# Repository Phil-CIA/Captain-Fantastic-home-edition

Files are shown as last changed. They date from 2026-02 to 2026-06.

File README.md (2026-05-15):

# Captain Fantastic – Home Edition

Firmware and hardware files for a restored Captain Fantastic pinball machine running on ESP32.

## Repository Layout

| Path | Description |
|---|---|
| `src/` `include/` `data/` | **Legacy firmware** – working single-board ESP32 firmware with External Flash OTA |
| `Captain-v2/` | **Captain v2 firmware** – clean split-MPU architecture (control + matrix boards) |
| `hardware/` | KiCad schematics, gerbers, and board-design backups |
| `docs/` | Project documentation, setup guides, and handoff notes |
| `archive/` | Historical backups, experiments, and recovery copies |
| `music/` | Test audio files used with the music streaming server |

## PlatformIO Projects

This repo contains **multiple PlatformIO projects**:

### 1. Legacy Firmware (root)
- `platformio.ini` at the repository root
- Active environment: `combined_rtos`
- Targets a single ESP32 running gameplay, displays, sound, and OTA

### 2. Captain v2 shared source tree
- `Captain-v2/platformio.ini`
- Shared build definitions and source for split-MPU firmware
- Includes environments for control, matrix, and display-link variants
- Shared source only; not the current matrix bring-up source of truth
- Separates control logic and switch/lamp matrix scanning across two ESP32 boards

### 3. Captain v2 board-specific projects
- `Captain-v2-control/platformio.ini` (control board focused project)
- `Captain-v2-matrix/platformio.ini` (matrix board focused project)
- Both reference shared source under `Captain-v2/` and keep board workflows isolated
- Current active board workflows:
	- Matrix board: `Captain-v2-matrix`, env `captain_matrix_idf`, COM4
	- Control board: `Captain-v2`, env `captain_control`, COM5

> **VS Code tip:** Open the specific project folder you are actively working on (`Captain-v2-control/` or `Captain-v2-matrix/`) so tasks and upload settings stay board-specific.

## Current Development Focus

- Active matrix bring-up/runtime source of truth is `Captain-v2-matrix/src/matrix_app_main.cpp`
- Matrix MCU appears on I2C as a register-based peripheral at `0x24` (HT16K33-style model)
- Matrix/control communication path is now usable for gameplay bring-up:
	- control-side polarity normalization and stability filtering restored usable switch behavior
	- repeated held-switch scoring was fixed
	- gameplay-side bumper / slingshot output mapping has been corrected
- Matrix protocol details and test workflow are documented in:
	- `Captain-v2-matrix/README.md`
- Remaining open issue is residual lamp flicker, but the structured blink component was traced to matrix-side periodic debug / housekeeping work in the refresh loop
- Current stop-point is good enough to continue gameplay bring-up while leaving a later focused flicker cleanup pass
- Hardware iteration note (March 2026): reduce the high-side rail voltage first to improve BSS84/BSS138 gate-drive margin before pursuing transistor substitutions (documented in `Captain-v2-matrix/README.md`, section 11)
- Redesign parking lot for next board iteration: `docs/NEXT_ITERATION_RECOMMENDATIONS.md`

## Music Streaming Server

`music_server.py` / `Start-MusicServer.ps1` stream audio to the pinball machine over Wi-Fi. See `docs/MP3_MUSIC_SETUP.md` and `docs/WIFI_STREAMING_SETUP.md` for setup.

## Documentation

All setup guides and reference docs are in `docs/`. See `docs/REPO_INDEX.md` for a full index.

## KiCad Current Project Entry Points

If KiCad is opening the wrong local copy, use only these repo project files:

- `hardware/kicad/captain_matrix/Pinball matrix board.kicad_pro`
- `hardware/kicad/captain_control/Pinball Control board.kicad_pro`
- `hardware/kicad/legacy/Hat board.kicad_pro` (historical reference project)

To keep KiCad focused on repo paths:

1. Launch with `Open-KiCad.ps1` from repo root.
2. Run `Reset-KiCad-Recents-ToRepo.ps1` once to clear stale KiCad recent/open project paths.
3. Use `hardware/kicad/SOURCE_OF_TRUTH.md` as the canonical board-path map.

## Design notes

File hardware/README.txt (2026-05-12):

This folder contains hardware design files, schematics, PCB layouts, and fabrication exports for Captain Fantastic v2.

Canonical project map and opening policy:
- kicad/SOURCE_OF_TRUTH.md

## Current Active Designs (v2 split-MPU architecture)

Structure:
- kicad/captain_control/: Main control board (ESP32 DevKit) — gameplay, audio, solenoids, headbox lamps, OTA
- kicad/captain_matrix/: Switch/lamp matrix board (ESP32 DevKit) — playfield matrix scanning, I2C slave
- kicad/7seg_display/: Standalone 7-segment display board (I2C HT16K33, 6-digit)

## Project support files
- kicad/libs/: project symbol/footprint libraries and KiCad tables

## Historical / Legacy
- kicad/legacy/: Hat board (superseded single-board v1 design — trace size and SR enable fixed in v2 split)
- kicad/esp32vroom/: Original ESP32Vroom KiCad project files (historical reference)

Important:
- Open active projects only from kicad/captain_control and kicad/captain_matrix.
- Treat kicad/legacy, kicad/esp32vroom, and archive/ as read-only historical sources.

## Fabrication archives
- gerbers/root-export-esp32vroom/: root-level export set moved from repo root
- gerbers/legacy-gerber-files/: older export set moved from "Gerber files"
- backups/esp32vroom-backups/: historical zipped hardware backups

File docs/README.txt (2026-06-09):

This folder contains documentation and reference files for the Captain Fantastic project.

Setup guides and reference docs:
- DISPLAY_SYSTEM_README.md, DISPLAY_BUFFER_REFERENCE.md, DISPLAY_IMPLEMENTATION_SUMMARY.md
- DIAGNOSTIC_TEST_MODE.md, SINGLE_DISPLAY_TEST.md, OLED_DISPLAY_ARCHITECTURE.md, VIRTUAL_DISPLAY_BUFFER.md
- EXTERNAL_FLASH_OTA_README.md, EXTERNAL_FLASH_OTA_INTEGRATION_COMPLETE.md, EXTERNAL_FLASH_OTA_LESSONS_LEARNED.md
- EXTERNAL_FLASH_OTA_INTEGRATION_EXAMPLE.cpp (code example/reference)
- WIFI_SETUP.md, WIFI_STREAMING_SETUP.md, MP3_MUSIC_SETUP.md, SOUND_SYSTEM.md, SOUND_MODEL.md
- LAMP_VOLTAGE_NOTES.md, POWER_NOTES.md, SWITCH_LAMP_MATRIX.md, SOLENOID_DRIVER_PCHANNEL.md
- W25Q64_SETUP_INSTRUCTIONS.md

Project organization:
- REPO_INDEX.md (full repository index)
- PROJECTS_MAP.md (project boundary map and cleanup rules)

Matrix board development:
- Captain-v2-matrix/README.md (datasheet-style matrix firmware contract)
- Captain-v2/include/matrix_test_support.h + Captain-v2/src/matrix_test_support.cpp (segmented matrix test harness)

Handoff notes:
- END_OF_DAY_HANDOFF_2026-03-26.rmd
- NEXT_CHAT_PROMPT_2026-03-26.txt

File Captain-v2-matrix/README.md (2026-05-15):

# Captain v2 Matrix Board Datasheet (Firmware Contract)

## 1. Purpose

This board is a dedicated switch/lamp matrix controller isolated from the main control board to reduce switching-noise coupling and provide a clean I2C break point.

The board presents itself on I2C like a peripheral IC (HT16K33-style behavior):
- Internal register/RAM map
- Command bytes for global control
- Master reads/writes registers instead of exchanging framed packets

## 2. Hardware Summary

### MCU
- ESP32-C6 (current PlatformIO target: `esp32-c6-devkitc-1`)

### I2C Interface
- Slave address: `0x24`
- SDA: GPIO2
- SCL: GPIO3
- Bus speed: 100 kHz

### Matrix Signals
- Switch columns (4 inputs): GPIO18, GPIO19, GPIO20, GPIO21

Rows are driven through the 74HC595 chain (not direct MCU row GPIOs).

### Lamp Shift Registers (74HC595 chain)
- DATA (DS): GPIO15 (`S_Data`)
- CLOCK (SHCP): GPIO22 (`S_CLK`)
- LATCH (STCP): GPIO23 (`S_latch`)
- OE# enable: GPIO10 (`SR_/OE`, active-low)
- Lamp columns mapped to SR bits 0..4

### Matrix OLED (diagnostic)
- Software I2C SDA: GPIO7
- Software I2C SCL: GPIO6

## 3. Functional Model

The firmware maintains:
- Lamp RAM: 8 rows, 1 byte per row (lower 5 bits used)
- Switch state bytes: 4 bytes packed from 8x4 switch matrix

The lamp scanner runs row-by-row. For each active row:
- Shift out column bits
- Enable row for a dwell period
- Move to next row

Global gates:
- System enable controls switch scanning and overall operation
- Output enable controls lamp output

If system or output is disabled, lamp output is forced off.

## 4. I2C Protocol (HT16K33-style)

### 4.1 Command Bytes

- `0x20` = System setup, disable
- `0x21` = System setup, enable
- `0x80` = Output setup, disable
- `0x81` = Output setup, enable
- `0xE0..0xEF` = Pulse-width level (low nibble = 0..15)

Pulse-width level is global (not per-lamp dimming).

### 4.2 Register Windows

- Lamp RAM: `0x00..0x07`
  - 8 bytes total (row 0..7)
  - Bits 0..4 = lamp columns 0..4
- Switch RAM: `0x40..0x43`
  - 4 bytes packed switch states from bit index `(row * 4 + col)`
- Diagnostics: `0xF0..0xF3`

### 4.3 Read/Write Behavior

Write transaction:
1. First byte selects command/register pointer.
2. Optional payload bytes write sequential registers.

Read transaction:
1. Master writes register pointer.
2. Master requests bytes.
3. Slave returns bytes from that window.

## 5. Diagnostics Registers (`0xF0..0xF3`)

- `0xF0`: status flags
  - Bit 0: system enabled
  - Bit 1: output enabled
  - Bit 2: test override active (test mode)
  - Bit 3: test auto-walk active (test mode)
- `0xF1`: current pulse-width level (0..15)
- `0xF2`: lamp row 0 value
- `0xF3`: switch byte 0 value

## 6. Lamp Pulse Width

Current implementation:
- `pulse_us = 50 + (level * 50)`
- Level range: 0..15
- Default level: 4 (250 us dwell)

This is intended as a coarse global brightness/current control. Typical operation is fixed level, not dynamic dimming.

## 7. Standalone Matrix Test Support (Removable)

Test support is intentionally isolated in:
- `Captain-v2/include/matrix_test_support.h`
- `Captain-v2/src/matrix_test_support.cpp`

Build control flag:
- `CAPTAIN_MATRIX_TEST_SUPPORT=1` enables interactive serial test commands.
- Set to `0` (or remove define) to disable test features.

### Serial Test Commands

- `HELP`
- `STATUS`
- `SYSTEM ON|OFF`
- `OUTPUT ON|OFF`
- `PULSE <0-15>`
- `ALL ON|OFF`
- `CLEAR`
- `ROW <0-7> <0-31>`
- `LAMP <row> <col> ON|OFF`
- `WALK ON|OFF`
- `SWITCHES`

## 8. Project Layout

This folder is a dedicated matrix-board PlatformIO project:
- `Captain-v2-matrix/platformio.ini`

It references shared source/include in `Captain-v2/` so matrix firmware and protocol stay centralized.

## 9. Minimal Master Example (Wire API)

```cpp
// Enable matrix device
Wire.beginTransmission(0x24); Wire.write(0x21); Wire.endTransmission();
Wire.beginTransmission(0x24); Wire.write(0x81); Wire.endTransmission();

// Set pulse width level = 4
Wire.beginTransmission(0x24); Wire.write(0xE4); Wire.endTransmission();

// Write lamp rows 0..7
uint8_t lampRows[8] = {0x00,0x02,0x02,0x02,0x00,0x00,0x00,0x00};
Wire.beginTransmission(0x24);
Wire.write(0x00);
Wire.write(lampRows, 8);
Wire.endTransmission();

// Read 4 switch bytes
Wire.beginTransmission(0x24);
Wire.write(0x40);
Wire.endTransmission(false);
Wire.requestFrom(0x24, 4);
```

## 10. Validation Checklist (No Control Board Required)

1. Confirm board responds at `0x24` on I2C scan.
2. Write `0x21` and `0x81`; verify lamp output can activate.
3. Write test lamp rows (`0x00..0x07`) and verify expected rows/columns.
4. Toggle physical switches and verify switch bytes (`0x40..0x43`) change.
5. Sweep pulse level (`0xE0..0xEF`) and verify visible/intensity timing behavior.
6. Read diagnostics (`0xF0..0xF3`) and confirm status bits/values.

## 11. Recommended Hardware Iteration (March 2026)

Decision: lower the high-side rail voltage instead of pushing the BSS84/BSS138 pre-driver stage closer to its voltage limits.

Reasoning from original design behavior:
- The original TIP125-based path tolerated a large conduction drop (`VCE` around 4 V in this use case).
- The current MOSFET path has much lower conduction drop (`VDS` typically below 0.2 V at 5 A for the selected device), which can increase effective stress elsewhere if the rail is left high.
- With measured rail excursions near 25.5 V, the small-signal gate-drive devices (BSS84/BSS138 stage) are at higher risk of gate overstress and non-deterministic turn-off behavior.

Practical guidance:
- Prefer rail reduction as the first hardware iteration.
- Re-validate ON/OFF gate-source voltages for the BSS84/BSS138 stage and the power MOSFET after rail adjustment.
- Keep this as a safety and reliability step before any component substitutions.

Cross-reference:
- Canonical redesign parking lot: `docs/NEXT_ITERATION_RECOMMENDATIONS.md`.
- Next-iteration handoff prompt: `NEXT_CHAT_PROMPT_2026-03-26.txt`.
- Top-level status summary: `README.md` (Current Development Focus).

## 12. Current Bring-Up Status (May 2026)

Current work moved to an intentionally stripped `bare-bones` firmware path to remove non-essential runtime influences (I2C service, switch scan, OLED updates, matrix scheduler complexity).

### Current verified status after May 14 communication fixes

- Active bring-up/runtime source of truth is `Captain-v2-matrix/src/matrix_app_main.cpp` with env `captain_matrix_idf`.
- Matrix/control register communication is now verified end-to-end.
- Control board no longer misreads lamp bytes as switch bytes.
- Matrix slave now preloads switch-register data after lamp writes so the next master read returns real switch bytes.
- Control-side repeated burst-filter spam was fixed by updating the previous-frame baseline even when an impossible burst frame is suppressed.
- Quick live mapping spot-check confirmed at least:
  - `S20 Outhole` -> row 0, col 0
  - `S9 Target 2` -> row 4, col 2
- Current normal control state after bring-up:
  - matrix-triggered actions enabled
  - manual START-button solenoid test remains disabled

### Remaining open items

1. Full switch-map re-walk is still incomplete.
2. Broader gameplay/coil soak validation after re-enable is still pending.
3. Decide later whether the expanded COM4 switch-byte heartbeat log should remain or be reduced.

### What was observed

- With several previous test images, row-selection appeared functional but column selection could collapse into whole-row activation.
- On live lamp rail, this can trip the 1.85 A polyfuse quickly when multiple lamps energize at once.
- To protect hardware, test flow now defaults to an output lockout state and uses short, low-duty experiments only.

### Safety baseline

- Bare-bones source: `Captain-v2-matrix/src/matrix_barebones_main.cpp`
- Active safety lockout control: `TEST_ENABLE_OUTPUTS`
  - `false` = OE# forced disabled (safe default)
  - `true` = explicit armed test mode

### Bare-bones environment

- PlatformIO environment: `captain_matrix_idf_barebones`
- Selection method: compile-time macro (`CAPTAIN_MATRIX_BAREBONES`) and source gating in `src/CMakeLists.txt`
- Note: for ESP-IDF projects, PlatformIO `src_filter` is not sufficient to select sources; use CMake + macros.

### Recommended next-session flow

1. Start with lamp rail disconnected and `TEST_ENABLE_OUTPUTS=false`.
2. Verify serial/logic behavior first (no lamp conduction).
3. Arm short low-duty tests only when ready (`TEST_ENABLE_OUTPUTS=true` with bounded window).
4. Reconnect lamp rail only for brief observations and cut power immediately if multi-lamp row activation appears.

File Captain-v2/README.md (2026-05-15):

# Captain v2 (split-MPU architecture)

This project is the clean start for the new hardware split:

- `captain_control`: gameplay, sound, display, solenoids, headbox lamps (`2x 74HC595`)
- `captain_matrix`: playfield switch/lamp matrix scan and I2C reporting

## Why this exists

The previous single-board design had switching-noise/ground-loop issues during attract mode. This version isolates matrix scanning and lamp drive on a dedicated MPU and sends matrix state to control via I2C.

## Environments

| Environment | Board | Role |
|---|---|---|
| `captain_control` | ESP32 DevKit | Main game controller (default) |
| `captain_control_ota`  | ESP32 DevKit | Same, OTA upload variant |
| `captain_matrix` | ESP32 DevKit | Switch/lamp matrix board |
| `captain_display` | ESP32-C6 | Display-board SPI slave |
| `captain_host_display` | ESP32-C6 | Host display-link SPI master |

Edit COM ports in `platformio.ini` as needed.

## UART Bring-Up Checklist (ESP32-C6 Matrix)

Use this checklist for current matrix board revisions.

1. Use `captain_matrix_c6_idf` environment.
2. Connect through UART bridge on `COM8` (TX, RX, GND).
3. Prefer UART port for flashing/monitoring; native USB is not the primary path on this board.
4. Close any existing serial monitor before upload.
5. Upload command:

```powershell
platformio run -e captain_matrix_c6_idf -t upload
```

6. Open monitor:

```powershell
platformio device monitor -p COM8 -b 115200
```

7. Expected success signature on reset:
	- `boot:0x1c (SPI_FAST_FLASH_BOOT)`
	- ESP-IDF bootloader lines
	- `app_init: Project name: Captain-v2`

8. If monitor says `waiting for download`, verify BOOT/GPIO9 is not asserted and ensure only one tool has COM8 open.

## SPI Handshake (display link)

Two extra GPIO lines added to the IDC ribbon between host and display ESP32-C6
boards for RTS/CTS-style flow control:

- **GPIO0 / IDC pin 5** — REQUEST (host → display)
- **GPIO1 / IDC pin 9** — READY   (display → host)

See `docs/SPI_HANDSHAKE.md` for full protocol description, timing diagrams,
and bring-up checklist.  Source: `include/spi_handshake_config.h`,
`include/spi_handshake.h`, `src/spi_handshake.cpp`.

## First migration pass included

- Display driver module copied from legacy (`HT16K33`)
- Shared control-matrix I2C protocol contract (`include/captain_protocol.h`)
- Shared canonical matrix mapping (`include/captain_mapping.h`)
- Clean entry points for both MPUs (`src/control_main.cpp`, `src/matrix_main.cpp`)

## Mapping status

- Switch matrix names and coordinates mapped from legacy firmware (`M1..M8` × `SW1..SW4`)
- Lamp matrix names and coordinates mapped from legacy firmware (`M1..M8` × lamp columns)
- Matrix GPIO pin map centralized in one file for both firmware targets
- Headbox `2x74HC595` lamp map is implemented from schematic (`Ball`, `Player`, `Tilt`, `Game Over`)
- Solenoid outputs are mapped to direct GPIO (not shift-register): `S2=GPIO23`, `S3=GPIO19`, `S4=GPIO18`, `S5=GPIO16`, `S6=GPIO17`
- Flash safety note: keep solenoid power removed while uploading firmware; avoid leaving coil power on during reset/flash windows.
- Four cabinet/control inputs moved off matrix to direct GPIO: `SW1=GPIO36`, `SW2=GPIO39`, `Tilt=GPIO34`, `Start=GPIO35`
- I2S audio output mapped for MAX98357A: `DIN=GPIO25`, `BCLK=GPIO14`, `LRCK=GPIO13`
- External SPI flash upgraded to `W25Q128` (16MB) with same SPI mapping: `CS=GPIO32`, `MOSI=GPIO26`, `MISO=GPIO27`, `SCK=GPIO33`
- I2C bus is shared by both devices: display (`0x70`) and matrix-board MCU (`0x24`) on `SDA=GPIO21`, `SCL=GPIO22`
- Matrix lamp commands now drive real lamp outputs on matrix board via local `74HC595` (`DS=GPIO2`, `SHCP=GPIO12`, `STCP=GPIO4`)
- Matrix switch labels for `Tilt` and `Start` are annotated as moved to direct GPIO inputs on control board

## Hardware Design Files

KiCad schematics and PCB layouts are organized under `../hardware/kicad/`:

| Board | Location | PlatformIO env | Purpose |
|---|---|---|---|
| **Pinball Control board** | `../hardware/kicad/captain_control/` | `captain_control` | Main game controller |
| **Pinball matrix board** | `../hardware/kicad/captain_matrix/` | `captain_matrix` | Playfield matrix scanner/lamp driver |
| **7-segment display** | `../hardware/kicad/7seg_display/` | — | Standalone I2C HT16K33 score display |
| **Hat board (legacy)** | `../hardware/kicad/legacy/` | — | Old single-board design (superseded v1) |

See `../docs/` for hardware documentation, design notes, and integration guides.

## Board-Specific Projects

Board-specific PlatformIO project folders live at the repository root for isolated bring-up and board-by-board work:

| Project folder | Purpose |
|---|---|
| `../Captain-v2-control/` | Separate PlatformIO project for the main control board firmware |
| `../Captain-v2-matrix/` | Separate PlatformIO project for the matrix board firmware and standalone test support |

Both folders point at the shared source tree under `Captain-v2/`, so firmware logic stays in one place while build/upload configuration stays isolated per board.

Matrix-board protocol and bring-up reference:
- `../Captain-v2-matrix/README.md` (datasheet-style firmware contract)

## Next

1. Replace placeholder pin maps in each `main` file.
2. Move verified game-state logic from legacy into `captain_control`.
3. Implement real matrix scan and lamp command execution in `captain_matrix`.
4. Implement headbox lamp control with `74HC595` in `captain_control`.

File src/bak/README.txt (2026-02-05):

This folder contains backup files (.bak) and old versions. Only keep current code in src/.

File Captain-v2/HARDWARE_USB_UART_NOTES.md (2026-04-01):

# Captain-v2 C6 USB/UART hardware notes (2026-04-01)

## Schematic conclusions
- ESP32-C6 native USB signals are on GPIO12 (D-) and GPIO13 (D+).
- Matrix board routing uses GPIO12/GPIO13 for lamp column signals.
- Because these pins are reused for matrix drive, native USB-Serial/JTAG is not reliable during normal matrix firmware operation.
- External UART bridge (CP2102 on UART0 TXD/RXD) is the correct debug/programming path for this board revision.

## Practical workflow
- Use `upload_port = COM8` and `monitor_port = COM8` for `captain_matrix_c6_idf`.
- Keep BOOT (GPIO9) released for normal run mode.
- If ROM says `waiting for download`, BOOT is held low or auto-download signaling is active.

## Critical mapping correction (2026-04-01)
- Root cause found during bring-up: connector pin numbering was interpreted upside-down.
- On this connector, numbering runs with pin 16 at the bottom and pin 30 at the top (reverse of earlier assumption).
- Because of that reversal, the net believed to be GPIO9 was actually a different pin location during probing.
- Always verify both net label and physical connector orientation before concluding strap-pin behavior.

## Confirmed boot strap conflict (2026-04-01)
- True GPIO9 is tied into `Sw_Col_3` switch input network through a 2.2k pull-down path.
- This is strong enough to hold the boot strap low at reset and force ROM download mode on-carrier.
- Practical impact: GPIO9 cannot be used as a normal switch column net on this board revision.
- Bring-up safeguard in firmware now excludes GPIO9 from active matrix column reads.

## Validated workaround (2026-04-01)
- Removing the resistor path on `Sw_Col_3` that pulled GPIO9 low restores normal `SPI_FAST_FLASH_BOOT` behavior on-carrier.
- After removal, runtime logs are stable and show continuous `captain_idf` alive ticks.
- This is a workable interim fix until full remap is implemented.

## Screenshot archival
- Dev board screenshots should be added under a folder such as `Captain-v2/docs/dev-board-schematics/` when available as image files.
- This note records the electrical conclusion even before images are committed.

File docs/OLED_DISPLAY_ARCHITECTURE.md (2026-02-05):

# OLED Display System - Architecture Documentation

## Overview
Captain Fantastic pinball machine display system using **5 × SSD1306 OLED displays (128×64 pixels each)** to mimic vintage 7-segment displays with authentic slanted/italicized segments.

## Hardware Configuration

### Displays
- **Type**: SSD1306 OLED (monochrome, 128×64 pixels)
- **Quantity**: 5 displays per row
- **Total Canvas**: 640 × 64 pixels (128px × 5)
- **Interface**: I2C (address 0x3C)
- **Multiplexer**: TCA9548A (address 0x70)

### Physical Layout
```
[Display 0][Display 1][Display 2][Display 3][Display 4]
 0-127px    128-255px  256-383px  384-511px  512-639px
```

### Original Display Reference
**Lumex LDS-C814** (or similar)
- 0.8" 7-segment display
- Character height: ~20mm
- Italicized/slanted segments (~10-12°)
- Segment width: ~2-3mm
- Character spacing: 9mm

## Display Architecture

### Character Layout
**6 characters per row** spanning 640 pixels:
- Character width: 74 pixels
- Character spacing: 33 pixels
- Total per character: 107 pixels
- Character height: 60 pixels (using 60 of 64 available)

**Character positions** (X coordinates):
```
Position 0: X=2
Position 1: X=109
Position 2: X=216  
Position 3: X=323
Position 4: X=430
Position 5: X=537
```

### Row Configuration
- **Row 0**: Player 1 score (6 digits)
- **Row 1**: Player 2 score (6 digits)
- **Row 2**: Player 3 score (6 digits)
- **Row 3**: Player 4 score (6 digits)
- **Row 4**: Status display (Player/Ball/Bonus)

## Virtual Pixel Buffer

### Buffer Structure
```cpp
uint8_t pixelBuffer[5120];  // 640×64 pixels = 5120 bytes (monochrome)
```

**Organization**: 
- 1 bit per pixel (monochrome)
- Organized as horizontal rows
- Byte packing: 8 pixels per byte

### Pixel Addressing
```cpp
// To set pixel at (x, y):
byteIndex = (y / 8) * BUFFER_WIDTH + x;
bitMask = 1 << (y % 8);
```

## 7-Segment Rendering

### Segment Layout (with slant)
```
       AAAA
      F    B
      F    B
       GGGG
      E    C
      E    C
       DDDD
```

**All segments have ~10-12° italic slant** to match vintage displays.

### Segment Dimensions
- **Length** (horizontal segments): 28 pixels
- **Height** (vertical segments): 24 pixels
- **Thickness**: 10 pixels
- **Slant offset**: 6 pixels horizontal

### Segment Positions
Relative to character origin (x, y):

**Horizontal segments** (A, G, D):
- Segment A (top): y=2 to y=12
- Segment G (middle): y=30 to y=40
- Segment D (bottom): y=58 to y=68 (actually 58-60 in 64px height)

**Vertical segments** (B, C, E, F):
- All slanted ~10-12° from vertical
- Top segments (F, B): y=0 to y=24
- Bottom segments (E, C): y=34 to y=58

### Character Patterns
Each character defined by segment pattern:
```cpp
struct SegmentPattern {
    bool segA, segB, segC, segD, segE, segF, segG, dp;
};
```

**Supported characters**:
- Digits: 0-9
- Hex: A-F
- Letters: C, E, L, U, P, b, d, u
- Special: blank, dash

## Display Update Pipeline

### Rendering Flow
1. **Clear pixel buffer** (optional)
2. **Render characters** → Virtual buffer
   - Convert character to segment pattern
   - Draw segments with slant
3. **Update physical displays** → I2C
   - Select multiplexer channel
   - Copy buffer region to display
   - Send to SSD1306

### Update Functions
```cpp
// High-level API
renderNumber(123456, false);       // Render 6-digit number
renderText("P1 b3", 0);            // Render text at position
renderCharAtPosition(2, '8');      // Single character

// Low-level
setPixel(x, y, true);              // Individual pixel
drawSlantedLine(x1, y1, x2, y2, thickness, color);
```

## Code Organization

### File Structure
```
include/
  displayFonts.h          - Character bitmap definitions & segment patterns
  displays.h              - Main display API & configuration
  displayMux.h            - TCA9548A multiplexer control
  
src/
  displays_oled.cpp       - OLED rendering implementation
  displayMux.cpp          - Multiplexer implementation
  main_oled_test.cpp      - Test program
```

### Key Components

**displayFonts.h**:
- Segment pattern definitions
- Character lookup table
- Rendering primitives

**displays.h**:
- Configuration constants
- Display API
- Buffer management

**displays_oled.cpp**:
- Pixel buffer operations
- Segment rendering (with slant)
- Character rendering
- Display update logic

## Configuration

### Scalability
Easily adapt to different configurations by changing:
```cpp
#define NUM_DISPLAYS 5           // Number of physical displays
#define NUM_CHARS_PER_ROW 6      // Characters per row
#define NUM_PLAYER_ROWS 4        // Number of player rows
#define HAS_STATUS_ROW true      // Enable status row
```

### I2C Settings
```cpp
Wire.begin(21, 22);              // SDA=21, SCL=22 (ESP32)
Wire.setClock(400000);           // 400kHz I2C fast mode
```

### Display Settings
```cpp
#define SSD1306_I2C_ADDRESS 0x3C
#define OLED_RESET -1            // No hardware reset pin
```

## Performance

### Timing
- **I2C speed**: 400kHz (fast mode)
- **Display update**: ~50-100ms per full refresh
- **Channel switching**: ~5ms delay between displays

### Memory Usage
- **Pixel buffer**: 5,120 bytes (640×64 pixels)
- **Display objects**: ~1KB per display × 5 = ~5KB
- **Total RAM**: ~10-15KB for display system

## Testing

### Test Commands
Send via Serial (115200 baud):
```
0-9  - Display specific digit
t    - Run full test sequence
s    - Test segment rendering
c    - Test character rendering
x    - Clear all displays
b    - Test brightness levels
p    - Print display mapping
d    - Dump pixel buffer stats
m    - Scan I2C multiplexer
?/h  - Help menu
```

### Test Sequence
1. Scan I2C channels (verify all displays detected)
2. Clear all displays
3. Count 0-9 with leading zeros
4. Display various numbers (123456, 999999, etc.)
5. Test all characters (letters, symbols)

## Future Enhancements

### Potential Improvements
1. **Row multiplexing** - Cycle between player rows if needed
2. **Animations** - Scrolling scores, transitions
3. **Custom characters** - Additional game-specific symbols
4. **Brightness control** - Per-display brightness adjustment
5. **Buffer optimization** - Dirty rectangle tracking
6. **Anti-aliasing** - Smooth segment edges
7. **Font variations** - Different segment styles/sizes

### Hardware Expansion
- Support for additional display rows
- Different display types (larger OLEDs)
- Color OLED displays
- Matrix/dot displays

## Comparison: Old vs New

### Original System (7-Segment)
- Physical 7-segment LED displays
- 7 segments + decimal point
- Simple segment patterns (8 bits)
- Limited character set
- Fixed appearance

### New OLED System
- SSD1306 pixel displays
- Full pixel control (640×64)
- Bitmap rendering
- Unlimited character possibilities
- Authentic vintage appearance with modern flexibility
- Scalable and configurable

## Summary
The OLED display system provides **authentic vintage 7-segment appearance** with the **flexibility of modern pixel displays**. By rendering slanted segments as bitmaps, we perfectly mimic the Lumex LDS-C814 style while gaining the ability to display any character or graphic needed for the game.

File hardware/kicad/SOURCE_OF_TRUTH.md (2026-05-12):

# KiCad Source Of Truth

This file is the canonical map for which KiCad project files are current in this repo.

## ⚡ Quick Start: How to Open Projects

**→ See [HOW-TO-OPEN-PROJECTS.md](HOW-TO-OPEN-PROJECTS.md) for step-by-step instructions**

(TL;DR: Use `Open-KiCad.bat` launcher or manually navigate to `hardware/kicad/` in KiCad's File → Open Project)

## Machine-Readable Data

Machine-readable companion file for agents/tools:
- `hardware/kicad/CURRENT_PROJECTS.yaml`

## Current Board Projects

1. Matrix board (active)
- Project: `hardware/kicad/captain_matrix/Pinball matrix board.kicad_pro`
- Fab anchor: Matrix board production set dated 2026-04-09.

2. Control board (active)
- Project: `hardware/kicad/captain_control/Pinball Control board.kicad_pro`
- Fab anchor: Control board production set dated 2026-04-11.

3. Hat board (historical reference)
- Project: `hardware/kicad/legacy/Hat board.kicad_pro`
- Fab anchor: Hat board production set dated 2026-03-16.

## Sequestered Historical Areas

Do not use these as active source locations:

- `archive/`
- `hardware/kicad/legacy/` (except when intentionally referencing old Hat design)
- `hardware/kicad/esp32vroom/`
- `hardware/gerbers/` (fabrication outputs only)

## Opening Policy

1. Launch KiCad from repo root with `Open-KiCad.ps1`.
2. If KiCad keeps opening old local paths, run `Reset-KiCad-Recents-ToRepo.ps1` once.
3. For current development edits, open only the project files listed in "Current Board Projects" above.

## Archive Policy

When superseding a board revision:

1. Keep the newest active revision under `hardware/kicad/<board_name>/`.
2. Move superseded revisions into an archive-labeled folder.
3. Do not reuse archive folders for active design work.
4. Update this file so future sessions can identify active files immediately.

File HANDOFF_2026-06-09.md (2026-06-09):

# Captain-Fantastic Handoff - 2026-06-09

## Session Outcome

This session focused on repo hygiene and documentation prep before returning to bench validation.

### Confirmed outcomes
1. Audio/game-mode issue draft exists and was updated as working planning guidance:
   - `docs/ISSUE_AUDIO_AND_GAME_MODES.md`
2. New sound-model documentation was added to describe current runtime behavior vs planned music path:
   - `docs/SOUND_MODEL.md`
3. Docs index now includes the new sound-model document:
   - `docs/README.txt`
4. No gameplay/control firmware code was changed in this session.

## Current Firmware Baseline (Unchanged)

- Control gameplay LED renderer remains on graphic-zone mapping.
- Intentional graphic-zone overlap remains preserved.
- Brightened gameplay palette remains active.
- Guarded control upload + COM12 hard block + MAC precheck remain mandatory.
- Last validated monitor runs still show warnings=0 from prior session baseline.

Primary active runtime targets are still:
- LED readability bench pass through all gameplay modes.
- Switch latency Phase 1 (control-only): `MATRIX_SWITCH_CONFIRM_POLLS 5 -> 2`.

## Documentation State Added/Updated

- Added: `docs/SOUND_MODEL.md`
- Added/updated: `docs/ISSUE_AUDIO_AND_GAME_MODES.md`
- Updated: `docs/README.txt`

## Notes For Next Session (Bench Start)

1. Start with guarded control upload only.
2. Run visual bench pass through modes:
   - attract
   - serve ball
   - ball in play
   - bonus countdown
   - game over
3. Run switch-health monitor for 120 seconds after each upload/validation pass.
4. If responsiveness still feels slow, execute switch latency Phase 1 in control only (`5 -> 2`) and re-validate.
5. Keep audio runtime wiring as separate scope from switch/LED bench verification.

## Suggested Commands Next Session

- `powershell -ExecutionPolicy Bypass -File scripts/guarded-flash.ps1 -Target control -Action upload`
- `powershell -ExecutionPolicy Bypass -File scripts/Monitor-SwitchHealth.ps1 -Port COM5 -DurationSeconds 120`

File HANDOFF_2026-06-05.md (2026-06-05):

# Captain-Fantastic Handoff - 2026-06-05

## Session Outcome

Session moved from planning and archaeology output into active control firmware implementation and validation for gameplay WS2812 behavior.

### Confirmed outcomes
1. Gameplay LED renderer was migrated to the user-provided graphic zone map in control firmware.
2. Graphic-zone overlap was explicitly accepted by user and preserved as intentional.
3. Post-integration firmware built and flashed successfully using guarded control upload.
4. Switch-health monitoring completed after flash with no warnings.
5. Palette was tuned brighter (higher channel floors, fewer dark hues) for visibility through painted glass.
6. Brightness-tuned firmware built and flashed successfully, followed by a second switch-health pass with no warnings.

## Current Firmware State (As Left)

### Control (Captain-v2)
File: Captain-v2/src/control_main.cpp

- Graphic-zone data structures and range tables are active for gameplay strip rendering.
- Mode renderer now paints via graphic zones:
  - attract
  - serve ball
  - ball in play
  - bonus countdown
  - game over
- Brighter color palette is now active across all gameplay modes to improve visibility through painted glass.
- Overlap entries in the zone table are intentionally retained per user direction.

### Safety / Flashing

Guarded flashing remained enforced:
1. COM12 hard block remained active.
2. Control target MAC precheck matched expected MAC on COM5.
3. Upload completed successfully after both integration and brightness tuning passes.

## Validation Evidence

### Compile/lint
- No errors reported for control file:
  - Captain-v2/src/control_main.cpp

### Uploads
- Guarded upload command/task succeeded twice for target control.

### Runtime monitor
- Monitor-SwitchHealth run after graphic-zone integration:
  - Samples=117, warnings=0
- Monitor-SwitchHealth run after bright-palette tuning:
  - Samples=118, warnings=0
- No fault or SPI fail counter regression observed during these checks.

## Files Changed This Session (Primary)

- Captain-v2/src/control_main.cpp
- HANDOFF_2026-06-05.md (new)
- NEXT_CHAT_PROMPT_2026-06-05.txt (updated)

## Notes For Next Session

1. Bench-check visual readability through glass in all game modes and confirm if another brightness step is needed.
2. If needed, add one global gameplay LED brightness bias scalar for quick tuning without per-mode color edits.
3. Keep guarded upload and switch-health monitoring mandatory for each LED validation cycle.

## Scope Update (Switch Latency Follow-Up)

1. New active scope: improve switch responsiveness with control-side debounce tuning first.
2. Phase 1 change target: `Captain-v2/src/control_main.cpp` only, reduce `MATRIX_SWITCH_CONFIRM_POLLS` from 5 to 2.
3. Constraint: do not lower control confirm polls below 2 in this phase.
4. Matrix side remains unchanged in Phase 1 to avoid introducing new false-trigger risk.
5. Phase 2 (only if needed after bench validation): matrix debounce may be reduced by one tick (4 -> 3), not to 2.

Issue draft created for tracking:
- `docs/ISSUE_SWITCH_LATENCY_CONTROL_5_TO_2.md`

## Suggested Commands Next Session

- powershell -ExecutionPolicy Bypass -File scripts/guarded-flash.ps1 -Target control -Action upload
- powershell -ExecutionPolicy Bypass -File scripts/Monitor-SwitchHealth.ps1 -Port COM5 -DurationSeconds 120

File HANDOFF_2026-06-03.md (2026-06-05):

# Captain-Fantastic-home-edition Handoff — 2026-06-03

## Session Outcome

Baseline recovery and safety standardization completed for split-MPU firmware:
- Matrix board recovered and flashed through guarded workflow on COM4.
- Control board recovered and flashed through guarded workflow on COM5.
- CrowPanel COM12 remained blocked throughout.
- Firmware identity stamping is now part of the standard (control boot prints build identity).

WS2812 strip state confirmed:
- GPIO15 strip path is live and verified on COM5.
- Control boot prints `Heartbeat enabled on GPIO15 (WS2812)`.
- The first pixel on the strip is responding from the same GPIO15 / TP8 net.
- Matrix RGB/status code remains a separate path and is not the focus for the next session.

## Standards Now In Effect

1. Guarded flash is mandatory for matrix/control uploads.
2. MAC identity is the primary guardrail.
3. COM12 is hard-blocked in this session workflow.
4. MAC mismatch requires explicit operator override (`-ForceMacMismatch`).
5. Control firmware must print build identity on boot (`git`, `state`, build timestamp).

## Key Files Added/Changed This Session

- Added: `scripts/guarded-flash.ps1`
- Added: `scripts/flash-targets.json`
- Added: `scripts/pio_build_meta.py`
- Modified: `.vscode/tasks.json`
- Modified: `Captain-v2/platformio.ini`
- Modified: `Captain-v2/src/control_main.cpp`
- Modified: `Captain-v2-matrix/platformio.ini`
- Modified: `HANDOFF_2026-05-15.md`

## Verified Hardware Identity (Current)

- Matrix target (COM4): `10:51:DB:FF:FE:0D:30:30`
- Control target (COM5): `44:1D:64:F8:2B:A0`

Source of truth: `scripts/flash-targets.json`.

## Known Good Commands

- Matrix build: `powershell -ExecutionPolicy Bypass -File scripts/guarded-flash.ps1 -Target matrix -Action build`
- Matrix upload: `powershell -ExecutionPolicy Bypass -File scripts/guarded-flash.ps1 -Target matrix -Action upload`
- Control build: `powershell -ExecutionPolicy Bypass -File scripts/guarded-flash.ps1 -Target control -Action build`
- Control upload: `powershell -ExecutionPolicy Bypass -File scripts/guarded-flash.ps1 -Target control -Action upload`

## Version Identity Behavior

Control setup now prints a line like:
- `Build: git=<short-hash> state=<clean|dirty> built=<date> <time>`

Implemented in:
- `Captain-v2/src/control_main.cpp`
- `scripts/pio_build_meta.py`

## Current Git State Snapshot

At handoff capture:
- HEAD: `7e1a312`
- Working tree includes modifications related to guard + version stamping, plus existing user changes in this branch.

## Tree Cleanup Completed (Archive-First, No Hard Deletes)

Archived artifacts were moved to:
- `archive/session-artifacts/2026-06-03/matrix-bak/`
- `archive/session-artifacts/2026-06-03/captain-v2-captures/`

Moved files:

1. Matrix backup artifacts
- `Captain-v2-matrix/src/matrix_app_main.cpp.bak-2026-05-05`
- `Captain-v2-matrix/src/matrix_app_main.cpp.bak-2026-05-12`
- `Captain-v2-matrix/src/matrix_app_main.cpp.bak-2026-05-13`

2. Captain-v2 capture artifacts
- `Captain-v2/capture.txt`
- `Captain-v2/serial_capture.txt`
- `Captain-v2/map_capture_short.txt`
- `Captain-v2/map_capture_sync.txt`
- `Captain-v2/map_capture_sync_smoketest.txt`
- `Captain-v2/map_capture_after_filter_fix.txt`

Notes:
- `pio_build_check.log` and `pio_upload_check.log` were not present at cleanup time.
- Build output directories remain intentionally untouched (`.pio/`, `Captain-v2/.pio/`) and can be purged later for disk cleanup if desired.

## Suggested Next Session Start

1. Resume from the 5/12 to 5/15 handoff set and compare the LED-related code changes directly.
2. Keep the scope on the WS2812 strip / LED restore path first, then decide whether any matrix RGB/status work is still needed.
3. Verify the current control boot output still reports the WS2812 GPIO15 line and build identity stamp.
4. Optionally purge generated `.pio/` directories if disk cleanup is needed.

## Safety Constraints

- Do not flash COM12/CrowPanel in this Captain session flow.
- Do not bypass MAC checks unless explicitly intended and acknowledged.
- Keep matrix and control uploads explicit by target and port.

## Tomorrow's Focus

The next session should use the 2026-05-12 through 2026-05-15 handoff trail to identify exactly which LED-related code changes are worth keeping.

Primary questions for tomorrow:
- What changed between the 5/12 WS2812 restore and the 5/15 flicker triage state?
- Which changes belong to the GPIO15 strip path and which are matrix-only diagnostics?
- Is any further restore actually needed, or is the control WS2812 path already the correct end state?

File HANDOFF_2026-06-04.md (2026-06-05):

# Captain-Fantastic Handoff - 2026-06-04

## Session Outcome

Session pivoted from recap into controlled LED/runtime A/B testing and then into GPIO15 strip routine expansion.

### Confirmed outcomes
1. Matrix periodic diagnostics were converted to explicit toggles and tested in single-variable and all-off combinations.
2. Best visual matrix lamp state today remained with all three periodic features off.
3. Control heartbeat on GPIO15 was fully disabled by policy (all modes off) and hardened with a feature gate.
4. Gameplay-driven GPIO15 WS2812 effects were added (non-blocking), then expanded from single-pixel to zone-mapped strip behavior with current limiting.
5. Switch recognition concern remains active; no hard failure observed, but user reported it may feel worse than before and asked to monitor while proceeding.

## Current Firmware State (As Left)

### Matrix (Captain-v2-matrix)
File: Captain-v2-matrix/src/matrix_app_main.cpp

- MATRIX_ENABLE_STATUS_HEARTBEAT = false
- MATRIX_ENABLE_LINK_LOG = false
- MATRIX_ENABLE_PERIODIC_IDLE_YIELD = false

These toggles are in the main loop and currently all disabled.

### Control (Captain-v2)
File: Captain-v2/src/control_main.cpp

- GPIO15 WS2812 chain length set to 301 pixels (D1 + external strip chain assumption)
- Heartbeat policy set OFF in all gameplay modes
- HEARTBEAT_FEATURE_ENABLED gate added so heartbeat is disabled at init when all mode flags are false
- Gameplay pulse engine added (non-blocking)
- Zone mapping added:
  - 6 zones
  - 20 pixels each
  - start at pixel 1 (strip-focused)
- Current limiting added:
  - channel clamp: GAMEPLAY_LED_MAX_CHANNEL = 40
  - estimated current budget: GAMEPLAY_LED_CURRENT_LIMIT_MA = 250
- Switch-to-zone mapping currently uses row/col index modulo zone count

### Bench observation from user
- Strip showed visible activity around first ~20 LEDs (not full strip)
- Gameplay behavior felt unchanged
- Switch recognition concern persisted (possibly worse, not confirmed)

## Safety / Flashing

Guarded flashing remained enforced throughout:
1. COM12 remained blocked.
2. Matrix uploads verified COM4 MAC target.
3. Control uploads verified COM5 MAC target.

## Monitoring Added

New script created: scripts/Monitor-SwitchHealth.ps1

Purpose:
- Watches control serial "Matrix link" summaries and highlights potential regression signals while LED work proceeds.

Default monitored fields:
- ready/fault
- wr_fail/rd_fail
- sup_le
- sw_edges

Example usage:
- powershell -ExecutionPolicy Bypass -File scripts/Monitor-SwitchHealth.ps1 -Port COM5 -DurationSeconds 120

Notes:
- Threshold for sup_le warning was tuned higher to reduce false positives.

## Files Changed This Session (Primary)

- Captain-v2-matrix/src/matrix_app_main.cpp
- Captain-v2/src/control_main.cpp
- scripts/Monitor-SwitchHealth.ps1 (new)

Other repo state at close also includes existing unrelated local changes and untracked files.

## User-Requested Direction Change

User requested closeout and reset plan because the path drifted from desired approach.

New direction:
1. Mine handoffs/docs/code history first.
2. Confirm whether LED routines from 2026-05-10 to 2026-05-15 already define intended zone/current-limit approach.
3. Check if relevant routines/history may be in another folder or repo.
4. If archaeology finds nothing decisive, restart strip routine design cleanly (similar to today but with stricter spec-first mapping).

## Reset Plan For Next Session

### Phase A - Archaeology First (No new behavior changes)
1. Re-read handoffs:
   - HANDOFF_2026-06-03.md
   - END_OF_DAY_HANDOFF_2026-05-10.rmd
   - END_OF_DAY_HANDOFF_2026-05-12.md
   - END_OF_DAY_HANDOFF_2026-05-13.md
   - END_OF_DAY_HANDOFF_2026-05-14.md
   - END_OF_DAY_HANDOFF_2026-05-15.md
2. Mine git history 2026-05-10..2026-05-15 for LED/switch routines in:
   - Captain-v2/src/control_main.cpp
   - Captain-v2-matrix/src/matrix_app_main.cpp
3. Expand search to likely adjacent folders in this repo that may have parallel implementation attempts:
   - Captain-v2-control/
   - display-firmware/
   - src/
   - include/
4. Cross-check second workspace repo for possible mixed implementation notes/routines:
   - WorkStation/

### Phase B - Decision Gate
1. If prior routines already match desired architecture, restore/adapt minimally.
2. If archaeology does not reveal suitable routines, start clean strip spec:
   - explicit segment map
   - explicit current budget
   - event-to-zone mapping table
   - switch regression watch required during each flash/test cycle

### Phase C - Regression Guard
1. Run Monitor-SwitchHealth.ps1 during every LED test pass.
2. Stop and investigate if ready/fault or fail counters regress materially.

## Suggested First Commands Next Session

- git -C "C:\Users\user\Esp32 projects VScode\Captain-Fantastic-home-edition" log --since="2026-05-10" --until="2026-05-16" --name-only -- Captain-v2/src/control_main.cpp Captain-v2-matrix/src/matrix_app_main.cpp
- powershell -ExecutionPolicy Bypass -File scripts/Monitor-SwitchHealth.ps1 -Port COM5 -DurationSeconds 120

## Open Questions

1. Is the external strip electrically/data-wise healthy beyond first ~20 LEDs (power injection, ground integrity, data integrity)?
2. Is switch recognition degradation real regression or workload/feel variance?
3. Should the zone map be physical-playfield mapped (lanes/targets/returns) rather than modulo-based mapping?

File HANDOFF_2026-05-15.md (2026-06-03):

# Captain-Fantastic-home-edition Handoff — May 15, 2026

## Mission Snapshot

Captain is back in a playable-enough bring-up state.

The state now is:
- switch transfer is working well enough for gameplay
- repeated held-switch scoring is fixed
- bumper / slingshot solenoid routing is corrected
- structured lamp blink was traced to matrix periodic debug work
- some baseline flicker remains, but it is no longer blocking progress

## Read This First

1. `END_OF_DAY_HANDOFF_2026-05-15.md`
2. `NEXT_CHAT_PROMPT_2026-05-15.txt`
3. `Captain-v2-matrix/src/matrix_app_main.cpp`
4. `Captain-v2/src/control_main.cpp`
5. `Captain-v2-matrix/README.md`
6. `Captain-v2/README.md`

## Current State

### Good
- COM4 matrix firmware builds and uploads from `Captain-v2-matrix`
- COM5 control firmware builds and uploads from `Captain-v2`
- switches feel good / acceptable again
- solenoids are mapped correctly again
- the obvious structured blink is mostly gone in the current matrix diagnostic state

### Not finished
- some baseline flicker still exists
- matrix periodic debug work is currently disabled as a diagnostic hold state
- user is willing to move on, but does not consider the flicker fully solved

## Immediate Next Task

Resume gameplay bring-up without destabilizing the current matrix/control baseline.

Definition of done for the next phase:
- keep the current switch feel and solenoid behavior intact
- continue gameplay validation and remaining mapping cleanup
- leave the matrix periodic-debug disables in place until there is a dedicated cleanup pass

## Constraints

1. Do not reopen broad switch-transfer surgery unless a concrete regression appears.
2. Do not assume the remaining baseline flicker is solved.
3. Keep matrix work anchored in `Captain-v2-matrix/src/matrix_app_main.cpp`.
4. When flicker work resumes later, start with refresh scheduling / `serviceI2C()` timing, not gameplay logic.

## Quick Commands

- Matrix upload: `pio run -e captain_matrix_idf -t upload --upload-port COM4`
- Control upload: `pio run -e captain_control -t upload --upload-port COM5`

## Guarded Upload Commands (MAC-Locked)

- Matrix build (guarded wrapper): `powershell -ExecutionPolicy Bypass -File scripts/guarded-flash.ps1 -Target matrix -Action build`
- Matrix upload (guarded wrapper): `powershell -ExecutionPolicy Bypass -File scripts/guarded-flash.ps1 -Target matrix -Action upload`
- Control build (guarded wrapper): `powershell -ExecutionPolicy Bypass -File scripts/guarded-flash.ps1 -Target control -Action build`
- Control upload (guarded wrapper): `powershell -ExecutionPolicy Bypass -File scripts/guarded-flash.ps1 -Target control -Action upload`

Session safety rules:
- COM12/CrowPanel is hard-blocked in this workflow.
- Upload precheck uses immutable MAC identity from `scripts/flash-targets.json`.
- MAC mismatch blocks upload unless operator explicitly passes `-ForceMacMismatch`.

## Build Identity Standard

- Control firmware now prints build identity at boot:
	- `git=<short-hash>`
	- `state=<clean|dirty>`
	- compile timestamp (`__DATE__ __TIME__`)
- Build metadata is injected by `scripts/pio_build_meta.py` via PlatformIO `extra_scripts`.
- This is now a standard paired with guarded flashing: every baseline flash should be both MAC-guarded and version-identifiable from serial boot logs.

## Status

**Current State**: 🟡 **Gameplay Bring-Up Resumed — Switches and Solenoids Usable, Baseline Flicker Deferred**

## Linked Files

- `END_OF_DAY_HANDOFF_2026-05-15.md`
- `NEXT_CHAT_PROMPT_2026-05-15.txt`

**Last Update**: May 15, 2026

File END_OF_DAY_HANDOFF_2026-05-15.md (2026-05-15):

# End Of Day Handoff - 2026-05-15

## Session Focus

Today completed the switch-transfer / gameplay bring-up pass far enough to get the machine into a usable state, then narrowed the remaining lamp artifact instead of continuing broad rewrites.

Primary goals were:
1. Restore trustworthy enough switch visibility on COM5 to resume gameplay bring-up.
2. Eliminate repeated held-switch scoring and obvious transport/polarity mistakes.
3. Correct gameplay-to-solenoid mapping errors found during live playfield tests.
4. Determine whether the remaining lamp blink/flicker was caused by periodic firmware work rather than the base lamp drive itself.
5. Leave a realistic stop-point because the machine is usable but not fully signed off.

## Executive Summary

### What is now known

1. **Matrix-to-control switch transfer is working well enough for gameplay.**
   - Raw switch bytes are reaching COM5.
   - Control-side polarity normalization now matches the real transport polarity.
   - Switches are visible again and user reports the current feel is good / acceptable.

2. **The repeated held-switch "machine gun" symptom was fixed on the control side.**
   - A second-stage control-side stability filter now latches presses immediately and confirms release over multiple polls.
   - Release confirmation was increased to reduce chatter-based retriggers.

3. **Gameplay switch handling is functional again.**
   - Presses now score on press instead of only after long or repeated holds.
   - Raw and filtered switch diagnostics on COM5 made it possible to prove the transport path instead of guessing.

4. **Bumper / slingshot solenoid routing was wrong and is now corrected.**
   - User confirmed the current solenoid behavior is good.

5. **The remaining structured lamp blink was caused by matrix-side periodic debug / housekeeping work in the refresh loop.**
   - Disabling the matrix status heartbeat changed the blink pattern.
   - Disabling the 2-second periodic idle yield nearly removed the blink.
   - Disabling the matrix link log removed the remaining obvious structured blink component.
   - This is the clearest root-cause signal found today.

6. **Some baseline flicker still exists, but the current state is acceptable enough to move on.**
   - User is not fully sold on the current lamp behavior.
   - User also explicitly said it is no longer bad enough to block moving forward.

## Current Runtime Truth

### Active projects / ports

- Matrix board project: `Captain-v2-matrix/`
- Matrix env: `captain_matrix_idf`
- Matrix board port: `COM4`
- Control board project: `Captain-v2/`
- Control env: `captain_control`
- Control board port: `COM5`

### Source of truth

- Matrix runtime source of truth: `Captain-v2-matrix/src/matrix_app_main.cpp`
- Control runtime source of truth: `Captain-v2/src/control_main.cpp`

## What Changed This Session

### 1) Restored switch publication and interpretation

The investigation stopped treating gameplay as the root cause and went back upstream to matrix publication and control acceptance.

Key changes:
- ensured fresh switch response publication after matrix scans
- added raw switch-byte visibility on COM5
- added control-side normalization so active-low transport becomes active-high gameplay bits

Result:
- COM5 now sees real switch transitions again
- gameplay events fire on press

### 2) Added control-side stability filtering to stop repeated counts

The main nuisance symptom after switch visibility returned was repeated scoring while a switch was held.

Control-side filtering was updated so:
- a press is accepted immediately
- release must remain stable across multiple polls before being considered real

Result:
- the "machine gun" behavior is gone
- switch feel stayed acceptable after the final tuning

### 3) Corrected gameplay output mapping

Live bench tests showed left/right sides were broadly correct, but bumper versus slingshot outputs were crossed.

Gameplay handler mappings in `Captain-v2/src/control_main.cpp` were corrected for:
- left slingshot / left bumper
- right slingshot / right bumper

Result:
- user confirmed the solenoids are now correct

### 4) Reduced matrix scan overhead without regressing switch feel too badly

Matrix dedicated switch scan timings were trimmed to the current best-balance state:
- blank = `100 us`
- settle = `100 us`
- release = `25 us`

An every-other-frame scan test was tried and rejected because it made switches and bumpers too sluggish.

Result:
- current scan timings are the best compromise found so far

### 5) Isolated the structured blink to matrix refresh-loop disturbances

This was the most important flicker finding of the day.

The matrix firmware had several periodic tasks running in the same main loop as lamp refresh:
- WS2812 status heartbeat
- periodic link logging
- a forced `vTaskDelay(1)` every `2,000,000 us`

Observed behavior during probes:
- after reducing matrix periodic work, the blink period changed instead of staying fixed
- when the `2 s` idle-yield path was disabled, the blink almost disappeared
- after the matrix link log was disabled, the obvious structured blink component was effectively gone

Conclusion:
- the distinct blink was not a lamp hardware mystery
- it was refresh interruption from debug / housekeeping work sharing the lamp loop

## Files Touched During The Session

### Matrix firmware
- `Captain-v2-matrix/src/matrix_app_main.cpp`
  - retained dedicated switch scan architecture
  - tuned switch scan timing to the current best compromise
  - disabled matrix status-heartbeat activity for diagnosis
  - disabled periodic idle-yield activity for diagnosis
  - disabled periodic matrix link logging for diagnosis

### Control firmware
- `Captain-v2/src/control_main.cpp`
  - added / tuned control-side switch normalization and filtering
  - improved raw vs filtered matrix diagnostics
  - reduced redundant lamp writes
  - corrected bumper / slingshot gameplay-to-solenoid mapping
  - left polling at the later slower test value that slightly helped flicker

## Current Working State

### Good

1. Matrix and control firmware both build and upload cleanly.
2. Switch visibility is back.
3. Repeated held-switch scoring is fixed.
4. Solenoid mapping is correct enough for gameplay bring-up.
5. Switch feel is currently good / acceptable.
6. The big structured blink was traced to matrix periodic debug work and is largely gone in the current diagnostic state.

### Still not ideal

1. There is still some baseline lamp flicker.
2. The current matrix firmware still contains bench-style diagnostic disables that should not be treated as the final architectural cleanup.
3. Spinner responsiveness is acceptable, but not fully polished.
4. The user is willing to move on, but is not calling the flicker solved.

## Important Current Diagnostic State

The matrix board is currently running with these periodic features disabled in `Captain-v2-matrix/src/matrix_app_main.cpp`:
- `MATRIX_ENABLE_STATUS_HEARTBEAT = false`
- `MATRIX_ENABLE_PERIODIC_IDLE_YIELD = false`
- `MATRIX_ENABLE_LINK_LOG = false`

This is intentional for diagnosis and should be treated as the current known-good-enough runtime, not as polished final behavior.

## Recommended Next Steps

### Immediate next work

1. Resume gameplay bring-up while preserving the current matrix diagnostic state.
2. Avoid reopening broad switch-transfer rewrites unless a new concrete regression appears.
3. Keep using the current matrix and control sources of truth rather than older shared-source assumptions.

### When returning to the flicker issue

4. Convert the periodic debug behaviors into explicit optional bench-only flags / build modes instead of leaving them as ad hoc edits in the main loop.
5. Measure whether `serviceI2C()` still causes visible refresh modulation under real control traffic.
6. If flicker is still worth chasing later, move the remaining investigation toward lamp-refresh ownership and scheduling boundaries, not switch polarity or gameplay logic.

## Suggested Restart Prompt

Continue from `END_OF_DAY_HANDOFF_2026-05-15.md`.

Current state: switch transport is working well enough for gameplay again, control-side polarity/filtering fixed the repeated-count problem, bumper/slingshot solenoid routing is corrected, and user says switches now feel good enough to move on. The remaining lamp issue is no longer a mysterious 1-second blink: today proved that the structured blink was caused by matrix-side periodic debug / housekeeping work inside `Captain-v2-matrix/src/matrix_app_main.cpp` (status heartbeat, link logging, and especially the 2-second idle yield). Those periodic tasks are currently disabled in the matrix firmware, which largely removed the structured blink, though some baseline flicker still exists. User is not fully satisfied with the lamp behavior, but it is no longer blocking progress. Next step is to preserve this state, move gameplay bring-up forward, and only later return to baseline flicker with a focused `serviceI2C()` / refresh-scheduling investigation.

## Agent-Readable Companion

Use `NEXT_CHAT_PROMPT_2026-05-15.txt` for the short restart version.

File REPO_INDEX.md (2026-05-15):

# Repository Index

## GitHub Repositories
1. Captain Fantastic Home Edition
   - https://github.com/Phil-CIA/Captain-Fantastic-home-edition
2. Development Station Power Supply
   - https://github.com/Phil-CIA/Development-Station-Power-Supply

## Captain Repository Layout
1. Legacy firmware
   - src/
   - include/
   - data/
   - docs/
   - docs/SYSTEM_BEHAVIOR_CONTRACT.md — working definition doc for state machine, scoring, audio, diagnostics, and pending design decisions
2. Captain-v2 split-MPU work
   - Captain-v2/
   - Captain-v2-control/
   - Captain-v2-matrix/
3. Hardware assets (Captain v2 split-MPU)
   - hardware/kicad/captain_control/ — Main control board schematic and PCB
   - hardware/kicad/captain_matrix/ — Switch/lamp matrix board schematic and PCB
   - hardware/kicad/7seg_display/ — Standalone 7-segment display board
   - hardware/kicad/legacy/ — Hat board (old single-board design, superseded)
   - hardware/kicad/esp32vroom/ — Original ESP32Vroom project (historical)
   - hardware/kicad/libs/ — Shared KiCad symbols and footprints
   - hardware/kicad/SOURCE_OF_TRUTH.md — Canonical current KiCad project map and archive policy
   - hardware/kicad/CURRENT_PROJECTS.yaml — Machine-readable current/historical KiCad path map for agents
   - hardware/gerbers/root-export-esp32vroom/ — Legacy gerber exports
   - hardware/gerbers/legacy-gerber-files/ — Older gerber exports
   - hardware/backups/esp32vroom-backups/ — Historical hardware backups
   - Open-KiCad.ps1 — Repo-safe KiCad launcher (manager/control/matrix/hat/7seg)
   - Reset-KiCad-Recents-ToRepo.ps1 — One-time KiCad recent/open-project reset to repo root
4. Archive material
   - archive/backups/
   - archive/battery-charger/
   - archive/rtos-main-firmware-restore/

## Current Firmware/Repo Status (updated 2026-05-14)
1. Matrix/control firmware link migrated to register-style I2C model (HT16K33-like operation)
2. Active matrix board source of truth is the dedicated project:
   - `Captain-v2-matrix/`
   - active runtime source: `Captain-v2-matrix/src/matrix_app_main.cpp`
3. Matrix board address: `0x24` on SDA=21/SCL=22
4. May 2026 bring-up fixes now verified:
   - COM5 no longer reads lamp bytes as switch bytes
   - matrix TX FIFO is preloaded with switch data after lamp writes
   - repeated control-side burst-filter spam fixed by updating baseline state on suppressed burst frames
   - quick live mapping spot-check confirmed `S20 Outhole` and `S9 Target 2`
5. Current normal control state after bring-up validation:
   - `MATRIX_SWITCH_MAPPING_MODE = false`
   - `MATRIX_SWITCH_SOLENOIDS_ENABLED = true`
   - `START_BUTTON_SOLENOID_TEST_ENABLED = false`
6. Matrix register windows implemented:
   - Lamp RAM `0x00..0x07`
   - Switch bytes `0x40..0x43`
   - Diagnostics `0xF0..0xF3`
7. Matrix standalone test support segmented into dedicated module:
   - `Captain-v2/include/matrix_test_support.h`
   - `Captain-v2/src/matrix_test_support.cpp`
8. Separate board-focused PlatformIO projects added:
   - `Captain-v2-control/`
   - `Captain-v2-matrix/`
9. Matrix board datasheet-style firmware contract added:
   - `Captain-v2-matrix/README.md`

## Local-Only Files That Should Stay Out Of GitHub
1. .pio/ build output
2. VS Code machine-specific files like c_cpp_properties.json and launch.json
3. LTspice generated outputs in Captain-v2/hw_sim/ (`*.raw`, `*.db`, `*.log`)

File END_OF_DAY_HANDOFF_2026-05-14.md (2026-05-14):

# End Of Day Handoff - 2026-05-14

## Session Focus

Today moved from gameplay implementation into matrix/control fault isolation.

Primary goals were:
1. Explain visible gameplay lamp flicker.
2. Determine whether COM5 was reading valid switch bytes from COM4.
3. Separate matrix lamp-drive problems from matrix switch-scan problems.
4. Leave the repo with a realistic current-state handoff instead of the earlier optimistic checkpoint.

## Executive Summary

### What is now known

1. **Lamp hardware path is good.**
   - A forced local L19 drive on the matrix board was solid.
   - That ruled out downstream lamp wiring, lamp power path, and the individual lamp driver path as the primary cause of the flicker.

2. **The old integrated matrix switch scan was disturbing lamp drive.**
   - With matrix switch scanning disabled, gameplay lamps stopped flickering.
   - This was the strongest proof that the scan architecture, not gameplay lamp ownership, was the source of the visual issue.

3. **Separating lamp refresh from switch acquisition fixed the lamp flicker.**
   - The matrix firmware was changed so lamp refresh and switch scanning are no longer performed in the same row phase.
   - Result: lamps now look good in normal operation.

4. **Ghost / false switch inputs still remain, but are reduced.**
   - False scoring and bonus increments still happen even after the lamp fix.
   - User disconnected solenoids for safety, but score/bonus still climb, confirming the ghost-input problem is still active.

5. **There is still evidence of protocol/readback corruption or mis-windowed reads.**
   - Repeated COM4/COM5 captures showed COM5 `sw0..sw3` values matching the first bytes of COM4 lamp data (`0x0C 0x16 0x04 ...`) rather than behaving like independent switch state.
   - Multiple attempts to reduce this were made. Improvement happened, but the issue is not fully eliminated.

## Current Runtime Truth

### Active projects / ports

- Matrix board project: `Captain-v2-matrix/`
- Matrix env: `captain_matrix_idf`
- Matrix board port: `COM4`
- Control board project: `Captain-v2/`
- Control env: `captain_control`
- Control board port: `COM5`

### Source of truth

- Matrix runtime source of truth: `Captain-v2-matrix/src/matrix_app_main.cpp`
- Control runtime source of truth: `Captain-v2/src/control_main.cpp`

## What Changed This Session

### 1) Reframed the problem from gameplay logic to matrix behavior

User reported:
- lamps visibly flickering during gameplay
- switch response requiring long holds
- repeated late counts / ghost inputs
- ball/bonus behavior being polluted by unreliable switch data

The investigation pivoted away from gameplay rules and into matrix firmware behavior.

### 2) Proved the lamp flicker was not caused by control-side lamp ownership

Control-side review showed L19 and other gameplay lamps were being commanded as steady lamps, not intentionally flashed.

The matrix row timing itself was much faster than visible flicker, so a slower modulation or scan coupling issue was suspected.

### 3) Forced-lamp probe on matrix board

A dedicated matrix-side diagnostic was added to force the L19 path locally.

Result:
- lamp was solid
- no flicker in forced-drive mode

Conclusion:
- the physical lamp path was not the root problem
- the normal scan/switch interaction was the real disturbance source

### 4) Separated lamp refresh from switch acquisition

Matrix firmware was changed so:
- lamp refresh continues row-by-row
- switch scanning runs in its own dedicated all-off pass instead of sharing the lamp row phase

This was the key architectural fix.

Result:
- lamps look good now
- visible flicker problem is effectively solved

### 5) Slowed and cleaned the dedicated switch scan pass

Switch scan timing was then adjusted with larger:
- blank time before sampling
- settle time with row asserted
- release time after each sampled row

Result:
- ghost inputs reduced somewhat
- not eliminated

### 6) Investigated matrix-side FIFO / response-window behavior

Repeated captures showed a suspicious pattern:
- COM4 lamp bytes: `lamp=[0C,16,04,1E,0C]`
- COM5 switch bytes: `sw0=0x0C sw1=0x16 sw2=0x04 sw3=0x00`

That strongly suggests the control board is still sometimes consuming lamp-frame-like data as switch bytes.

Matrix-side experiments performed:
- preloading switch response window after switch scan
- removing unsolicited preloading per user request
- simplifying fallback response behavior

Result:
- some improvement, but not a full fix
- user explicitly preferred removing clever FIFO behavior rather than relying on preloads

### 7) Added a control-side guard against lamp-echo switch reads

Control firmware now rejects a switch frame if it exactly matches the first four bytes of the most recently transmitted lamp frame.

This reduces one known bad readback pattern and adds a summary counter (`sup_le`) for visibility.

Result:
- did not fully clear the ghost-input problem
- confirms there is still a deeper issue beyond that one obvious echo case

## Files Touched This Session

### Matrix firmware
- `Captain-v2-matrix/src/matrix_app_main.cpp`
  - removed integrated switch sampling from lamp refresh
  - restored dedicated switch scan pass
  - increased switch scan blank/settle/release timing
  - experimented with switch-response FIFO handling
  - simplified matrix-side response preload behavior

### Control firmware
- `Captain-v2/src/control_main.cpp`
  - added score-display update guard (test only; not root cause)
  - added lamp-echo switch-read suppression
  - added `sup_le` visibility in matrix link summary

### Matrix config / build recovery
- `Captain-v2-matrix/sdkconfig.captain_matrix_idf`
  - adjusted during build recovery to get the real matrix project building again under PlatformIO/ESP-IDF

## What Is Working Now

1. COM4 real matrix firmware is restored and buildable from `Captain-v2-matrix`.
2. COM5 control firmware builds and uploads normally.
3. Lamps look good in gameplay.
4. The forced-lamp diagnostic proved the lamp path is healthy.
5. Separate lamp/switch scan architecture is in place.

## What Is Not Solved Yet

### Primary open issue

**Ghost switch inputs still exist.**

Observed by user as:
- score increments without real playfield hits
- bonus increments without intended switch events
- earlier coil activations before solenoids were disconnected

### Strong current hypotheses

1. **Switch readback path is still not fully trustworthy.**
   - COM5 switch bytes still resemble COM4 lamp bytes too closely in repeated captures.

2. **There may still be a matrix-side slave-response / request-order problem.**
   - The protocol may be too permissive about what is present in the slave TX path when the master requests switch registers.

3. **There may also be a real switch-matrix bias / polarity issue layered on top.**
   - The remaining ghost inputs are reduced, not unchanged, so more than one mechanism may be involved.

## Important Negative Findings

These are now effectively ruled out as primary root causes:

1. Gameplay lamp logic in `control_main.cpp`
2. Simple 10 Hz score-display rewrite as the main lamp-flicker source
3. Downstream lamp wiring / single-lamp hardware path failure
4. “All flicker is just because the matrix scan rate is too slow”

## Current Safety State

- User disconnected solenoids for now.
- This was the right move while ghost inputs are still present.
- Do **not** re-enable normal coil testing until switch-state trust is improved.

## Recommended Next Steps

### Highest priority

1. Instrument the actual switch-register request/response path more aggressively.
   - Prove what COM4 thinks it is returning for `0x40..0x43` at the moment COM5 requests it.
   - Prove what COM5 requested immediately before each bad read.

2. Add one narrow protocol sanity check on the control side.
   - If switch bytes equal a known impossible or lamp-like pattern, ignore them and log them.
   - Keep solenoids disabled while doing this.

3. Confirm whether the remaining bad frames are:
   - stable repeating patterns
   - or truly random patterns

### After protocol truth is established

4. If the protocol path is clean, move to physical switch bias investigation:
   - row polarity
   - column pull-up behavior
   - discharge time between sampled rows
   - whether switch columns need stronger pull-ups or different scan polarity assumptions

## Suggested Restart Prompt

Continue from `END_OF_DAY_HANDOFF_2026-05-14.md`.

The lamp flicker issue is effectively solved by separating matrix lamp refresh from switch scanning in `Captain-v2-matrix/src/matrix_app_main.cpp`. The remaining blocker is ghost switch input: score and bonus still increment without valid hits, even though lamps are now stable. Repeated COM4/COM5 captures still suggest COM5 sometimes sees switch bytes that numerically resemble COM4 lamp bytes (`0x0C 0x16 0x04 ...`). Solenoids are intentionally disconnected by the user for safety. Next step is protocol-truth instrumentation of the matrix switch-register request/response path before making broader electrical assumptions.

## Agent-Readable Companion

Use `NEXT_CHAT_PROMPT_2026-05-14.txt` for the short restart version.

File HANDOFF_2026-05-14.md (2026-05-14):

# Captain-Fantastic-home-edition Handoff — May 14, 2026

## Mission Snapshot

Captain is active again and the immediate problem is no longer “get any matrix firmware running.”

The state now is narrower and more concrete:
- matrix/control builds are working
- matrix lamp flicker has been materially fixed
- ghost switch input is still the blocker

## Read This First

1. `END_OF_DAY_HANDOFF_2026-05-14.md`
2. `NEXT_CHAT_PROMPT_2026-05-14.txt`
3. `Captain-v2-matrix/README.md`
4. `Captain-v2/README.md`
5. `Captain-v2-matrix/src/matrix_app_main.cpp`
6. `Captain-v2/src/control_main.cpp`

## Current State

### Good
- COM4 matrix firmware builds and uploads from `Captain-v2-matrix`
- COM5 control firmware builds and uploads from `Captain-v2`
- gameplay lamps now look good
- integrated lamp/switch scan coupling is no longer the main lamp issue

### Bad
- ghost switch inputs remain
- score and bonus can still increment without legitimate switch hits
- user currently has solenoids disconnected for safety

## What Was Proven

1. Lamp hardware path is healthy.
2. Matrix lamp flicker was caused by the combined lamp/switch scan path.
3. Separating lamp refresh from switch scan fixed the visible lamp issue.
4. Remaining false input is not solved yet.
5. COM4/COM5 captures still suggest switch-read corruption or lamp-data contamination somewhere in the path.

## Working Theory

The main unresolved issue is now one of these two classes:

1. protocol/readback truth problem between matrix slave response and control-board switch reads
2. real switch-matrix electrical bias / polarity problem that remains after the scan separation

Do not assume either one is already proven. The current evidence still points more strongly to the protocol/readback side.

## Active Environments / Ports

- Matrix project: `Captain-v2-matrix/`
- Matrix env: `captain_matrix_idf`
- Matrix port: `COM4`

- Control project: `Captain-v2/`
- Control env: `captain_control`
- Control port: `COM5`

## Immediate Next Task

Do a protocol-truth pass, not another broad matrix rewrite.

Definition of done:
- prove exactly what COM4 returns for switch-register reads at request time
- prove exactly what COM5 asked for before each suspect frame
- determine whether remaining ghost frames are lamp-echo shaped, stable stuck patterns, or genuine noisy switch patterns

## Constraints

1. Keep solenoids disconnected until ghost inputs are trustworthy.
2. Do not reopen broad gameplay changes while switch truth is unresolved.
3. Keep matrix work anchored in `Captain-v2-matrix/src/matrix_app_main.cpp`.
4. Prefer logging / instrumentation over more speculative timing changes.

## Quick Commands

- Matrix upload: `pio run -e captain_matrix_idf -t upload --upload-port COM4`
- Control upload: `pio run -e captain_control -t upload --upload-port COM5`

## Status

**Current State**: 🟡 **Active Bring-Up — Lamps Stable, Ghost Switch Input Still Blocking Gameplay Validation**

## Linked Files

- `END_OF_DAY_HANDOFF_2026-05-14.md`
- `NEXT_CHAT_PROMPT_2026-05-14.txt`

**Last Update**: May 14, 2026

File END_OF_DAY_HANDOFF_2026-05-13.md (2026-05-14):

# End Of Day Handoff - 2026-05-13

## Session Focus

Today focused on two items:
1. Verify that switch-to-solenoid mapping was not accidentally wrong.
2. Recover matrix board boot stability so matrix heartbeat and switch traffic can resume.

## What Was Completed

### 1) Mapping sanity check on control firmware

Verified control dispatch in Captain-v2/src/control_main.cpp is internally consistent with Captain-v2/include/captain_mapping.h:
- row0,col0 -> S2 pulse path (outhole handling)
- row2,col1 -> S3
- row3,col1 -> S4
- row1,col3 -> S5
- row4,col3 -> S6

Also confirmed rows 6-7 are still masked in readMatrixSwitches(), so undefined matrix rows do not drive coils.

### 2) Matrix reboot-loop root cause identified and fixed

Observed recurring boot crash on COM4:
- Detected size(4096k) smaller than binary header(8192k)
- assert failed: __esp_system_init_fn_init_flash

Root cause:
- Flash size config mismatch in upload/build path (board still treated as 8MB even after partial config edits).

Fix applied:
- Captain-v2/platformio.ini (env captain_matrix_c6_idf):
  - board_build.flash_size = 4MB
  - board_upload.flash_size = 4MB
- Captain-v2/sdkconfig.captain_matrix_c6_idf:
  - CONFIG_ESPTOOLPY_FLASHSIZE_4MB=y
  - CONFIG_ESPTOOLPY_FLASHSIZE="4MB"

Validation:
- Clean erase/upload on COM4 succeeded.
- Boot log now reports SPI Flash Size : 4MB.
- Flash-size mismatch assert no longer appears.

### 3) Why heartbeat LED was not visible

Heartbeat confusion resolved:
- Active compiled source for Captain-v2 matrix IDF env is src/idf_main.cpp (set by src/CMakeLists.txt).
- That file currently has no status LED heartbeat code.
- GPIO8 is used in that active row pin map, so onboard WS2812 heartbeat on GPIO8 is not available in current scaffold mapping.

Note:
- A heartbeat implementation was added to src/idf_matrix_main.cpp, but that file is not currently compiled by Captain-v2/src/CMakeLists.txt.

## Files Touched Today

- Captain-v2/platformio.ini
- Captain-v2/sdkconfig.captain_matrix_c6_idf
- Captain-v2/src/idf_matrix_main.cpp

## Current Hardware/Runtime State

- Control board upload path on COM5 is working.
- Matrix board on COM4 now boots clean (no flash assert loop).
- Matrix heartbeat LED still not visible in active scaffold because status LED code is not in currently compiled entrypoint and GPIO8 is consumed by row mapping there.

## Open Items For Next Session

1. Decide heartbeat strategy for matrix board:
   - Option A: Keep current row map and use serial heartbeat only.
   - Option B: Free GPIO8 from row mapping and add WS2812 heartbeat in src/idf_main.cpp.
2. Resume clean switch mapping capture now that matrix is stable again.
3. Confirm matrix link from control returns ready=1 under normal run after reboot fix.

## Suggested Restart Prompt

Continue from END_OF_DAY_HANDOFF_2026-05-13.md.

Matrix flash-size reboot loop is fixed (4MB config + upload override). Next, implement chosen matrix heartbeat path in the active Captain-v2 ESP-IDF entrypoint (src/idf_main.cpp), then run a clean switch mapping capture and confirm control reports matrix ready=1.

## Gameplay Integration Next Steps - 2026-05-14

Goal remains the same: merge the recovered hardware/transport path with the existing gameplay firmware so the machine runs a real gameplay loop end-to-end.

### Where We Are Now

- Matrix board on COM4 boots clean after the 4MB flash-size fix.
- Control board on COM5 already has the gameplay firmware concentrated in Captain-v2/src/control_main.cpp.
- control_main.cpp already contains switch-to-solenoid dispatch, score accumulation, headbox lamp updates, direct-input handling, and tone/audio feedback.
- Remaining blockers are hardware/runtime validation, not large new gameplay-code invention.

### Immediate Priority Order

1. Re-confirm the hardware foundation after the May 13 reboot fix:
   - Flash both boards fresh.
   - Confirm control serial shows matrix ready=1 / linkHealthy=true.
   - Confirm wr_ok and rd_ok counters increment monotonically.
2. Close the matrix heartbeat decision:
   - Option A: keep the current row map and use serial heartbeat only.
   - Option B: free GPIO8 and add WS2812 heartbeat in Captain-v2/src/idf_main.cpp.
3. Run clean switch mapping capture:
   - 30s quiet baseline.
   - 15-20 deliberate presses on at least 3 switches.
   - Compare current behavior against known-good checkpoint aca9ac0.
   - Gate: one dominant bit per press and no suppression by burst filtering.
4. Verify S2 outhole relay status:
   - If relay workaround is not fully installed, finish bench wiring and validate force recovery.
   - If still pending, keep S2 protection limits enforced and do not treat gameplay as fully validated.
5. Validate direct inputs under live polling:
   - START, TILT, SW1, SW2.
   - 20 presses each, zero missed detections, zero false positives.

### Gameplay Bring-Up Sequence After Gates Pass

1. Confirm control board is running the intended Arduino gameplay target, not an IDF scaffold.
2. Press START and verify:
   - score reset
   - attract/headbox behavior starts cleanly
   - expected startup tone/audio path works
3. Trigger representative matrix switches and verify each full path:
   - switch edge detected
   - expected solenoid fires
   - score increments
   - lamp frame updates propagate correctly
4. Press TILT and verify:
   - tilt latches
   - gameplay behavior aborts as expected
   - solenoid behavior respects tilt state
5. Run a 5-minute soak:
   - no link faults
   - no dropped real switch events
   - no spurious coil activity

### Milestone Definition

This milestone is complete when the machine demonstrates at least one stable end-to-end gameplay flow:
- START input works.
- At least one switch-to-solenoid path works reliably.
- Score changes correctly.
- Lamps update correctly.
- Control-to-matrix link stays healthy during continuous run.

### Scope Boundaries

- Do not widen scope into multiplayer, multiball, or full audio-content migration yet.
- Do not treat ESP-IDF scaffolds as the gameplay merge target; control_main.cpp remains the main gameplay path.
- Focus on proving one stable playable loop first, then expand features after that baseline is locked.

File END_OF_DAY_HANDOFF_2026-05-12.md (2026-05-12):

# End Of Day Handoff - 2026-05-12

## Session Overview

Today focused on **heartbeat LED restoration** after discovering the matrix board's green LED had stopped blinking. The session uncovered and fixed two separate pin-conflict issues—one on the control board and one on the matrix board—and validated I2C communication end-to-end.

---

## What Was Completed

### 1. ✅ Identified Root Cause: Matrix Board LED Not Blinking
- **Problem**: Matrix-board (ESP32-C6 on COM4) green LED was solid green, not blinking as expected.
- **Root cause discovery**: The matrix firmware `logLinkHeartbeat()` was logging status every 1000ms over serial, but there was **no hardware LED driver implementation** in the active firmware.
- **Control board side issue** (bonus): Discovered heartbeat pin on control board (GPIO2) conflicted with headbox 74HC595 data line, so heartbeat was silently disabled there.

### 2. ✅ Fixed Control Board Heartbeat Pin Conflict
- **File**: [Captain-v2/src/control_main.cpp](Captain-v2/src/control_main.cpp#L26)
- **Change**: Moved heartbeat pin from GPIO2 (conflicted with `CAPTAIN_HEADBOX_595_DATA_PIN`) to GPIO16 (free).
- **Build**: Compiled and uploaded to COM5 successfully.
- **Result**: Control board now has heartbeat capability on GPIO16 (user has its own RGB LED, so visual indicator less critical than on matrix board).

### 3. ✅ Implemented Matrix Board WS2812 Heartbeat (GPIO8, RMT)
- **Files Modified**:
  - [Captain-v2-matrix/src/matrix_app_main.cpp](Captain-v2-matrix/src/matrix_app_main.cpp)
  - [Captain-v2-matrix/src/CMakeLists.txt](Captain-v2-matrix/src/CMakeLists.txt)
- **Approach**: Native ESP-IDF RMT driver (no external component dependency).
- **Implementation**:
  - `initStatusHeartbeatLed()`: Initialize RMT TX channel + bytes encoder for WS2812 protocol.
  - `updateStatusHeartbeatLed()`: Toggle green pixel (0, 24, 0) every 500ms.
  - `writeStatusLedColor()`: Non-blocking RMT transmit to WS2812.
- **Integration**: Called in main loop after each heartbeat log event.
- **Build**: Successful compile and upload to COM4.
- **Runtime Validation**: No RMT timeout errors; matrix link counters continue incrementing cleanly.

### 4. ✅ Validated I2C Link Health End-to-End
- **Control Board (COM5)**: Link counters `wr_ok` and `rd_ok` incrementing at ~60–70 pkt/s.
- **Matrix Board (COM4)**: Link counters `rx_pkts`, `lamp_bursts`, `lamp_bytes` all increasing consistently.
- **Status**: `ready=1`, `fault=0`, `wr_fail=0`, `rd_fail=0` (no I2C errors).
- **Conclusion**: I2C communication is **stable and healthy**.

### 5. ✅ Clean Firmware State After Changes
- No temporary diagnostics left in code.
- No debug-only flags enabled.
- Both boards running production baseline.

---

## Files Changed This Session

### Captain-v2/src/control_main.cpp
- **Line 26**: Changed `HEARTBEAT_PIN` from `2` to `16`.
- **Impact**: Control board heartbeat now active on GPIO16 (no longer conflicts with headbox shift-register).

### Captain-v2-matrix/src/matrix_app_main.cpp
- **Lines 13**: Added `#include "driver/rmt_encoder.h"` and `#include "driver/rmt_tx.h"`.
- **Line 26**: Added `constexpr uint32_t MATRIX_STATUS_HEARTBEAT_MS = 500;`.
- **Line 27**: Added `constexpr gpio_num_t MATRIX_STATUS_RGB_PIN = GPIO_NUM_8;`.
- **Lines 95–98**: Added RMT channel and encoder handles + status LED state variables.
- **Lines 761–777**: Implemented `writeStatusLedColor()` (non-blocking RMT transmit).
- **Lines 780–822**: Implemented `initStatusHeartbeatLed()` (RMT channel + encoder setup).
- **Lines 825–842**: Implemented `updateStatusHeartbeatLed()` (500ms toggle logic).
- **Line 925**: Added `initStatusHeartbeatLed()` call during app startup.
- **Line 1015**: Added `updateStatusHeartbeatLed()` call in main event loop.

### Captain-v2-matrix/src/CMakeLists.txt
- Removed temporary `REQUIRES led_strip` (component not available; using native RMT instead).

---

## Known Issues

### 1. ⚠️ Unused Function Warning (Non-Critical)
- `scanSwitchMatrix()` defined but not used in `matrix_app_main.cpp`.
- **Status**: Low priority. Can be removed or wrapped in `#if 0` during cleanup.
- **Impact**: Compilation succeeds; no runtime effect.

### 2. ⚠️ Matrix LED Not Yet Visually Confirmed
- Firmware initialized successfully and logs show no errors.
- LED heartbeat code is in place and should toggle GPIO8 every 500ms.
- **Next step**: Physically inspect matrix board LED to confirm green blink pattern.

### 3. ⚠️ Control Board Heartbeat on GPIO16 Not Visually Confirmed
- Pin reassignment successful; firmware compiled and uploaded.
- Control board has its own RGB LED on COM5 (user mentioned it has one), so GPIO16 heartbeat may not drive the visible LED.
- **Clarification needed**: Is the RGB LED on control board wired to GPIO16, or does it use a different pin?

---

## I2C Link Status Summary

### Control Board (COM5)
```
Matrix link: ready=1 fault=0 wr_ok=267 wr_fail=0 rd_ok=267 rd_fail=0
Matrix link: ready=1 fault=0 wr_ok=333 wr_fail=0 rd_ok=333 rd_fail=0
```
- Write/read counters incrementing steadily (~1 pkt/sec per 1-second log interval = ~67 pkt/s observed).
- No write or read failures.
- Link ready and stable.

### Matrix Board (COM4)
```
I (4995) captain_matrix: link rx_pkts=295 lamp_bursts=295 lamp_bytes=2354 ... sw0=0xFF
I (5995) captain_matrix: link rx_pkts=361 lamp_bursts=361 lamp_bytes=2882 ... sw0=0xFF
I (6995) captain_matrix: link rx_pkts=427 lamp_bursts=427 lamp_bytes=3410 ... sw0=0xFF
```
- Packet count incrementing by ~66 packets per second.
- Lamp burst and byte counts tracking together (valid).
- No errors or faults in serial logs.

---

## Potential Steps for Tomorrow

### Priority 1: Verify Heartbeat LED Visibility
1. **Matrix board (COM4)**: Inspect GPIO8 to confirm green LED is blinking at ~1 Hz.
   - If blinking: ✅ Feature complete; move to Priority 2.
   - If not blinking: Check hardware connection to WS2812 LED; may need to remap to different GPIO.

2. **Control board (COM5)**: Clarify if control board's RGB LED is connected to GPIO16.
   - If yes: Check if LED is blinking with new heartbeat.
   - If no: Identify correct RGB LED pin and update `HEARTBEAT_PIN` in control firmware.

### Priority 2: Address Unused Function Warning
- Remove or conditionally disable `scanSwitchMatrix()` in `matrix_app_main.cpp` to clean up compiler output.

### Priority 3: Extended I2C Stability Test
- Run a 5–10 minute continuous capture on both COM4 and COM5 to confirm link stability under sustained load.
- Verify no counter rollovers or error spikes.

### Priority 4: Switch Mapping Validation (Resumed from Previous Session)
- From prior handoff: Single-switch bit-dominance capture and mapping mode were pending.
- If time permits after LED verification, resume switch isolation testing to lock mapping.

### Priority 5: Pulse Points & Timing Markers (Optional)
- From prior discussion: Consider adding GPIO phase markers for oscilloscope validation.
- Current timing constants are stable; markers would be for bench verification only.

---

## Hardware Configuration Reference

### Matrix Board (ESP32-C6 on COM4)
- **Status LED**: GPIO8 (WS2812 via RMT)
- **I2C Address**: 0x24 (slave)
- **I2C SDA**: GPIO2, **SCL**: GPIO3
- **OLED SDA**: GPIO7, **SCL**: GPIO6 (diagnostic display, optional)
- **Matrix Rows**: GPIO0–7
- **Matrix Columns**: GPIO18, 19, 20, 21
- **Shift Register (Lamp Drive)**: DATA=GPIO15, CLOCK=GPIO22, LATCH=GPIO23
- **Environment**: ESP-IDF, PlatformIO env `captain_matrix_idf`

### Control Board (ESP32 on COM5)
- **Heartbeat GPIO**: GPIO16 (updated today)
- **I2C Address**: Master on SDA=21, SCL=22
- **Headbox 74HC595**: DATA=GPIO2 (restored), CLOCK=GPIO12, LATCH=GPIO4
- **Environment**: Arduino, PlatformIO env `captain_control`

---

## Build & Upload Commands

### Matrix Board
```bash
cd C:\CaptainMatrixBuildCheck\Captain-v2-matrix
platformio run -e captain_matrix_idf -t upload --upload-port COM4
```

### Control Board
```bash
cd C:\CaptainMatrixBuildCheck\Captain-v2
platformio run -e captain_control -t upload --upload-port COM5
```

---

## Testing Notes

### Serial Capture (Raw)
**Matrix (COM4, 115200 baud):**
```
I (xxxx) captain_matrix: link rx_pkts=295 lamp_bursts=295 lamp_bytes=2354 last_cmd=0x00 pulse_us=600 lamp=[...] sw0=0xFF
```

**Control (COM5, 115200 baud):**
```
Matrix link: ready=1 fault=0 wr_ok=267 wr_fail=0 rd_ok=267 rd_fail=0 diag_warn=0 sw0=0x... ...
```

### Expected Heartbeat LED Behavior
- **Matrix board**: Green LED on GPIO8 should toggle every 500ms (1 Hz blink frequency).
- **Control board**: GPIO16 should output a 1 Hz square wave (500ms high, 500ms low).

---

## Lessons Learned

1. **Pin Conflict Detection**: Always cross-check GPIO assignments against all module configs (headbox, matrix, I2C, etc.). Conflicts can silently disable features without explicit errors.

2. **Native RMT is Robust**: ESP-IDF's native RMT TX driver + bytes encoder handles WS2812 protocol cleanly without external component dependencies. Non-blocking transmit eliminates timeout spam.

3. **I2C Stability**: Consistent packet flow and error-free counters indicate the link is solid. Ready to focus on application-layer features next.

---

## Commits This Session

- **Commit 1**: Move control board heartbeat pin from GPIO2 → GPIO16 (resolve 74HC595 conflict)
- **Commit 2**: Implement matrix board WS2812 heartbeat on GPIO8 (RMT-based, non-blocking)
- **Commit 3**: Add this handoff document for tomorrow's continuation

---

## Resumption Checklist for Tomorrow

- [ ] Physically verify matrix board LED blinks green at 1 Hz
- [ ] Physically verify control board GPIO16 heartbeat toggle (or confirm RGB LED driver pin)
- [ ] Run extended I2C stability test (5–10 min capture)
- [ ] Remove `scanSwitchMatrix()` unused function warning
- [ ] (Optional) Resume switch mapping validation if LED tests pass quickly

---

## Summary

**Today's Win**: Heartbeat LED support restored on both boards. I2C link confirmed stable and healthy. Ready to move forward with application features or debugging (switch isolation, timing markers, gameplay logic).

**Key Files to Review Tomorrow**:
- [Captain-v2-matrix/src/matrix_app_main.cpp](Captain-v2-matrix/src/matrix_app_main.cpp) (lines 26–27, 95–98, 761–842, 925, 1015)
- [Captain-v2/src/control_main.cpp](Captain-v2/src/control_main.cpp) (line 26)

**No Blockers**: Both firmware builds succeed, upload succeeds, runtime is clean.

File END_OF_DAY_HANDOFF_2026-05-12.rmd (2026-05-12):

# End-of-Day Handoff — May 12, 2026 (Afternoon)

## Session Summary

**Objective**: Escape diagnostic rabbit hole and establish formal timing contract + documentation discipline

**Outcome**: ✅ **SUCCESS** — Baseline revalidated, timing contract locked, documentation infrastructure created

**Duration**: ~2 hours (including tool installation and full build cycle)

---

## Firmware State

| Metric | Value |
|---|---|
| Current file | `Captain-v2-matrix/src/matrix_app_main.cpp` |
| Restored from | `matrix_app_main.cpp.bak-2026-05-05` |
| Build environment | `captain_matrix_idf` (ESP32-C6, ESP-IDF) |
| Upload status | ✅ SUCCESS to COM4 |
| Upload port | COM4 (115200 baud) |
| Control port | COM5 (ESP32 Arduino, 115200 baud) |

---

## Phase 1: Baseline Revalidation — ✅ PASS

**Process**:
1. Located `.bak-2026-05-05` in repo
2. Restored to active `matrix_app_main.cpp`
3. Built with `platformio run -e captain_matrix_idf`
4. Uploaded to COM4 via esptool
5. Ran 30-second serial capture on COM5

**Acceptance Test Results**:

| Criterion | Result | Value |
|---|---|---|
| sw0 toggling | ✅ PASS | 0x00 ↔ 0xFF observed |
| sw1 toggling | ✅ PASS | 0x00 ↔ 0xFF observed |
| sw2 toggling | ✅ PASS | 0x00 ↔ 0xFF observed |
| sw3 toggling | ✅ PASS | 0x00 ↔ 0xFF observed |
| Link ready | ✅ PASS | ready=1 (all 27 samples) |
| Link fault | ✅ PASS | fault=0 (all 27 samples) |
| Packet rate | ✅ PASS | ~63 pkt/sec (target 60–80) |
| wr_ok delta | ✅ PASS | +1876 over 30s |
| rd_ok delta | ✅ PASS | +1876 over 30s |
| Checksum failures | ✅ PASS | 0 (no link errors) |

**Baseline Verdict**: **WORKING** — All critical switches active, I2C link stable, no errors.

---

## Phase 2: Timing Contract Definition — ✅ COMPLETE

**Created**: `docs/TIMING_CONTRACT_2026-05-12.md`

**Content**:
- Core timing constants extracted from `.bak-2026-05-05`
- Shift register configuration (active-HIGH, col-then-row chain)
- I2C interface spec (0x24, 100 kHz, GPIO2/3)
- Acceptance criteria for future validation
- Baseline test results documented
- Future measurement notes (for scope/LA work next session)

**Key Constants (Locked)**:
- `MATRIX_ROW_SETTLE_US` = 50 µs
- `MATRIX_SWITCH_DEBOUNCE_TICKS` = 4
- `MATRIX_LAMP_PULSE_MIN_US` = 100 µs
- `MATRIX_LAMP_PULSE_STEP_US` = 100 µs
- Shift register: active-HIGH rows/columns, col-then-row chain

**Critical Discovery**: May 5 baseline uses **ACTIVE_LOW logic for switch reading** (simple: `const bool closed = (level == 0)`), not the diagnostic overrides in May 10 experimental code.

---

## Phase 3: Documentation Discipline Setup — ✅ COMPLETE

### 3a. Resource Table
**Created**: `docs/RESOURCE_TABLE.csv`

**Content**: Timeline of firmware versions with resource snapshot

| Date | Firmware | Status | Key Notes |
|---|---|---|---|
| 2026-05-05 | `.bak-2026-05-05` | PASS | Baseline: switches + lamps working |
| 2026-05-10 | Current (before restore) | FAIL | Experimental: diagnostic hacks, wrong polarity, debounce forced to 1 |
| 2026-05-12 | Restored from `.bak-2026-05-05` | PASS | Baseline revalidated, acceptance test PASS |

### 3b. Development Workflow
**Created**: `docs/DEVELOPMENT_WORKFLOW.md`

**Establishes**:
- Restore & validate workflow (new session checklist)
- Daily backup naming convention (`.bak-YYYY-MM-DD`)
- Git commit discipline (descriptive messages with timing constants)
- Resource table update triggers
- Timing contract review points
- Handoff template

### 3c. Daily Backup
**Created**: `matrix_app_main.cpp.bak-2026-05-12`

Copy of validated baseline at end of this session.

---

## Documentation Created/Updated

| File | Type | Purpose |
|---|---|---|
| `docs/TIMING_CONTRACT_2026-05-12.md` | NEW | Timing spec + acceptance criteria (locked baseline) |
| `docs/RESOURCE_TABLE.csv` | NEW | Resource audit timeline across handoffs |
| `docs/DEVELOPMENT_WORKFLOW.md` | NEW | Backup discipline, restore checklist, documentation procedures |
| `Captain-v2-matrix/src/matrix_app_main.cpp.bak-2026-05-12` | NEW | Daily backup of validated state |

---

## Key Findings & Insights

### What Was Wrong in May 10 Code
1. **Polarity mismatch**: `MATRIX_SWITCH_ACTIVE_LOW = false` (should be true for hardware)
2. **Debounce override**: `MATRIX_SWITCH_DEBOUNCE_TICKS` macro-forced to 1 (diagnostic hack)
3. **Timing changes**: `ROW_SETTLE_US` changed from 50 to 300 (unnecessary)
4. **Result**: Switches appeared non-responsive, but hardware was fine

### What's Correct in May 5 Baseline
1. **Active-LOW logic**: Simple `const bool closed = (level == 0)` — matches hardware (pull-up inputs)
2. **Reasonable debounce**: 4 ticks = stable threshold without overdamping
3. **Conservative timing**: 50 µs settle = safe margin above clock jitter
4. **No diagnostic hacks**: Clean, production-ready code

### The Rabbit Hole
- Previous sessions added more diagnostic instrumentation to debug the "broken" switches
- But the switches weren't broken — the polarity flag was inverted
- Once restored to May 5, everything worked immediately
- **Lesson**: Validate baseline before iterating on diagnostics

---

## Acceptance Criteria (Locked for Future Reference)

When validating any new firmware build, **all** of these must be true:

1. ✅ **Link ready**: `ready=1`, `fault=0`
2. ✅ **Switch data**: `sw0..sw3` bytes toggle (not stuck at 0x00 or 0xFF indefinitely)
3. ✅ **Debounce**: No chatter within 4-tick window (stable state transitions)
4. ✅ **I2C health**: `wr_ok` and `rd_ok` counters increment continuously
5. ✅ **Packet rate**: 60–80 packets/sec (steady-state I2C traffic)
6. ✅ **No errors**: Zero checksum failures, no link rejects
7. ✅ **RGB status**: Blue LED (GPIO8, no fault state)

---

## Next Session Should

### If Making Changes
1. Start from [docs/DEVELOPMENT_WORKFLOW.md](DEVELOPMENT_WORKFLOW.md) **restore & validate workflow**
2. Make your code changes
3. Run acceptance test per [docs/TIMING_CONTRACT_2026-05-12.md](TIMING_CONTRACT_2026-05-12.md)
4. Create `.bak-YYYY-MM-DD` backup and `git commit`
5. Update `RESOURCE_TABLE.csv` with results

### For Scope/Logic Analyzer Work
1. Review [docs/TIMING_CONTRACT_2026-05-12.md](TIMING_CONTRACT_2026-05-12.md) section: **Future Measurement Notes**
2. Capture waveforms for:
   - Row strobe timing (GPIO22 clock vs. GPIO18..21 sample)
   - Column sample hold duration
   - Lamp pulse width vs. brightness level
   - **Critical**: Row-to-column phase offset (was 5–20 ms in May 4, should be < 1 ms now)
3. Document measurements in new timing contract version
4. Update acceptance criteria if limits need adjustment

### For Adding Features
- **Do not proceed until** timing contract scope measurements are complete
- Changing timing constants requires scope validation + timing contract update
- Add new features only after baseline is locked and measured

---

## Known Issues / Tech Debt

- ❌ Column-driver conduction not visually confirmed (lamps may not be illuminating despite valid digital signals)
- ❌ 5–20 ms row-to-column phase offset noted in May 4 scope capture (needs re-measurement with baseline)
- ❌ Switch mapping not yet isolated (multiple bits active per row; needs post-debounce filtering)
- ⚠️ OLED diagnostics disabled in baseline (kept off to preserve timing continuity)
- ⚠️ No scope/LA measurements for timing contract (placeholder for next session)

**These are NOT blockers for current baseline** — all listed above are improvements for future sessions, not defects in the validated baseline state.

---

## Git Status

**Files staged for commit** (if applicable):
```
Captain-v2-matrix/src/matrix_app_main.cpp (restored from .bak-2026-05-05)
Captain-v2-matrix/src/matrix_app_main.cpp.bak-2026-05-12 (NEW)
docs/TIMING_CONTRACT_2026-05-12.md (NEW)
docs/RESOURCE_TABLE.csv (NEW)
docs/DEVELOPMENT_WORKFLOW.md (NEW)
END_OF_DAY_HANDOFF_2026-05-12.rmd (THIS FILE)
```

**Recommended commit message**:
```
2026-05-12: Establish timing contract & documentation discipline

- Restore May 5 baseline (baseline revalidated, acceptance test PASS)
- Extract timing constants to TIMING_CONTRACT_2026-05-12.md (locked spec)
- Create RESOURCE_TABLE.csv for cross-handoff resource tracking
- Create DEVELOPMENT_WORKFLOW.md for backup discipline + restore checklist
- Document that May 10 diagnostic code had polarity/debounce errors
- Baseline ready for scope measurements and feature work

Timing locked: ROW_SETTLE=50µs, DEBOUNCE=4, LAMP_PULSE_MIN=100µs
Acceptance test: PASS (all switches toggling, link stable, no errors)
Next: Scope/LA measurements to validate phase offset and waveforms
```

---

## Session Metrics

- **Build time**: ~18 seconds (platformio compile + upload)
- **Testing time**: 30 seconds (acceptance test capture)
- **Documentation time**: ~60 minutes
- **Total wall-clock**: ~2 hours including tool setup

---

## References

- **Baseline firmware**: `Captain-v2-matrix/src/matrix_app_main.cpp.bak-2026-05-05`
- **Timing spec**: [docs/TIMING_CONTRACT_2026-05-12.md](TIMING_CONTRACT_2026-05-12.md)
- **Resource table**: [docs/RESOURCE_TABLE.csv](RESOURCE_TABLE.csv)
- **Development process**: [docs/DEVELOPMENT_WORKFLOW.md](DEVELOPMENT_WORKFLOW.md)
- **Hardware pinout**: [docs/GPIO_PINOUT.md](GPIO_PINOUT.md)
- **Previous baseline context**: `END_OF_DAY_HANDOFF_2026-05-05.rmd`

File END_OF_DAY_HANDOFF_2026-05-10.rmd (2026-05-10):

# End Of Day Handoff - 2026-05-10

## Session Outcome

Today ended with a stable matrix-control communication link, but switch isolation/mapping is still not clean enough to trust for gameplay logic.

You were right to pause here.

## What Was Completed

1. Matrix board (COM4, ESP32-C6, ESP-IDF) is running the split protocol path successfully.
2. Control board (COM5, ESP32) is successfully communicating with matrix at 0x24.
3. Matrix board status RGB LED was implemented on dev-board onboard LED path (GPIO 8, WS2812 timing via native RMT).
4. False red flashes were reduced by tightening error signaling:
   - Red LED now tracks hard checksum-fail conditions (not benign merged-stream rejects).
   - Lamp write reject handling was narrowed to malformed base-frame writes.
5. Extended telemetry checks passed repeatedly:
   - rx_pkts increasing on matrix
   - wr_ok and rd_ok increasing on control
   - lamp_chkfail steady at 0
   - lamp_reject steady at 0 after parser adjustment
6. A temporary control-side mapping mode was added:
   - MATRIX_SWITCH_MAPPING_MODE = true in Captain-v2/src/control_main.cpp
   - This forces lamp frame off during mapping attempts to reduce scan coupling noise.
7. captain_control was built and uploaded to COM5 after that change.

## Current Stable Truth

1. Transport and protocol path are healthy and believable.
2. Matrix link is ready and counter movement is consistent.
3. Data-integrity alarms are no longer firing spuriously.
4. The unresolved issue is switch isolation/noise, not I2C communications.

## What Is Still Failing

A/B mapping attempts (baseline vs repeated target-switch pressing) still fail to produce one dominant switch bit with acceptable separation.

Observed pattern:
- Multiple bits in sw0 rise in both baseline and press windows.
- Press window does not produce enough signal separation over noise floor.
- Burst filter dropped counts are still present, though improved after lamp-off mapping mode.

## Files Changed This Session

1. Captain-v2-matrix/src/matrix_app_main.cpp
   - Added status RGB handling (RMT WS2812)
   - Adjusted red-fault trigger behavior
   - Narrowed reject-count logic for lamp writes
2. Captain-v2/src/control_main.cpp
   - Added MATRIX_SWITCH_MAPPING_MODE and forced lamps off in writeMatrixCommand while enabled

## Morning Restart Plan

1. Keep current firmware baseline (do not roll back).
2. Start with quiet 30s capture on COM5 and record:
   - sw0 unique values
   - dropped totals
   - sw_edges max
3. Run focused single-switch capture (15 to 20 deliberate presses) using the known-good parse script format used today.
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

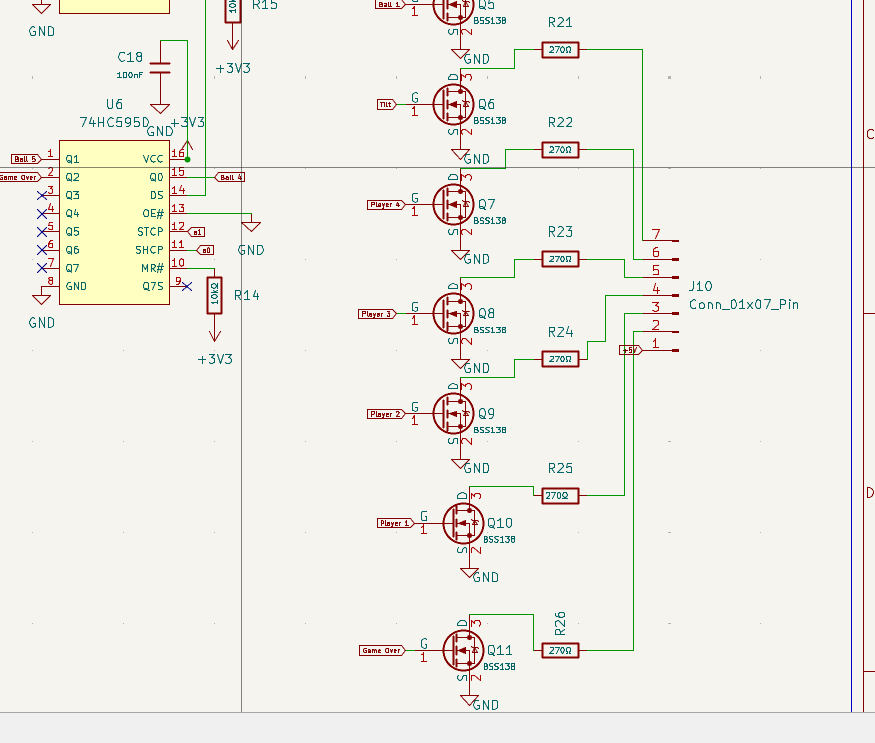
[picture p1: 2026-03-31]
hardware/kicad/captain_control/screenshots/Screenshot 2026-03-31 093441.png

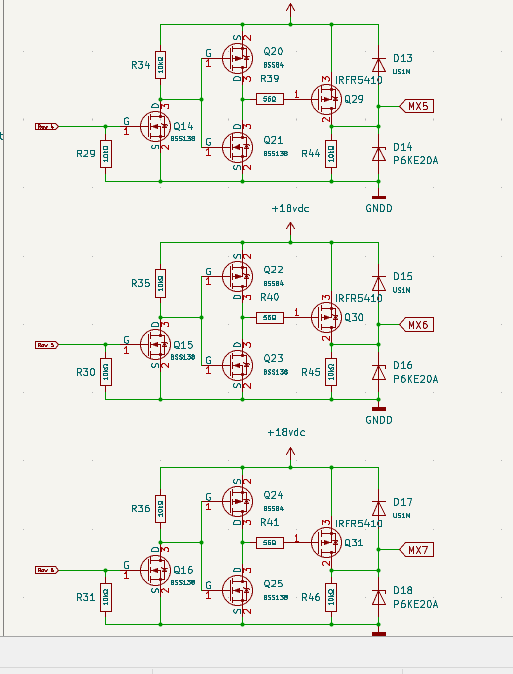
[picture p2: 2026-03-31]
hardware/kicad/captain_matrix/screenshots/Screenshot 2026-03-31 090232.png

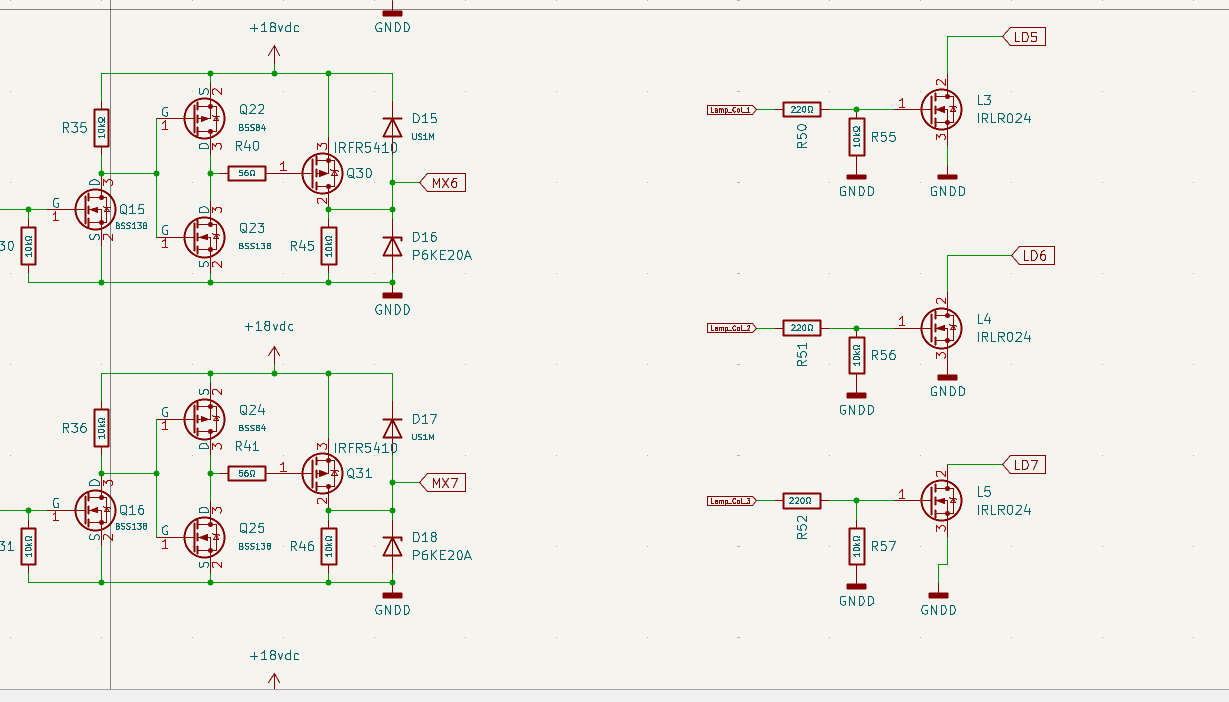
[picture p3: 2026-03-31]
hardware/kicad/captain_matrix/screenshots/Screenshot 2026-03-31 090341.png

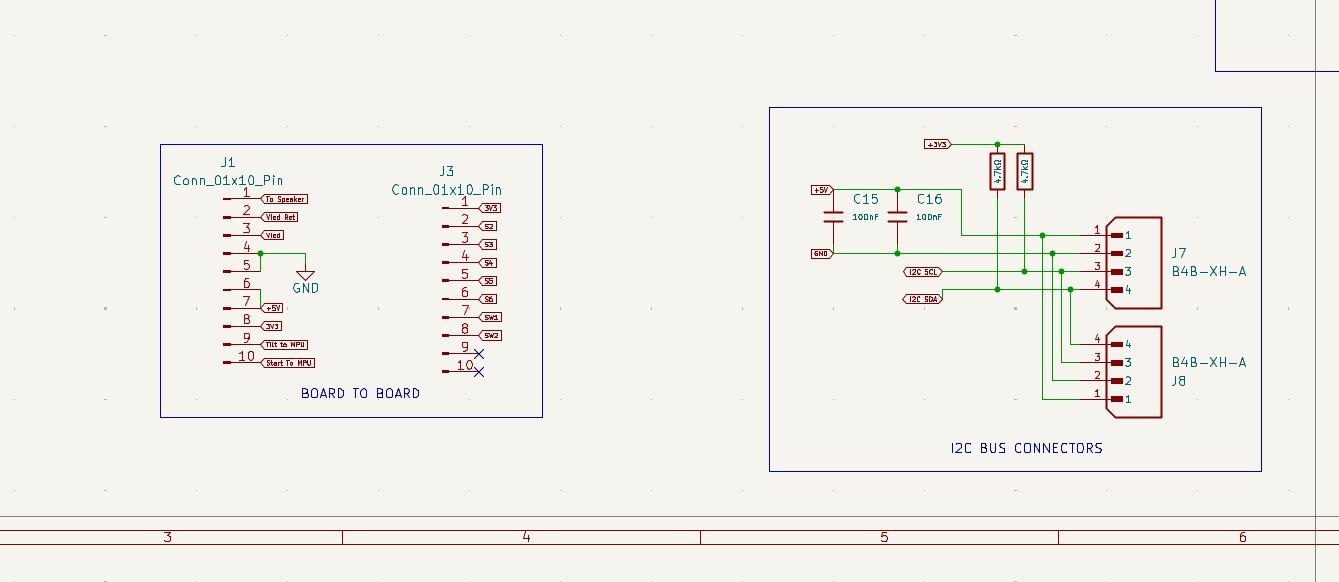
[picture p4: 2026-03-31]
hardware/kicad/captain_control/screenshots/Screenshot 2026-03-31 093525.png

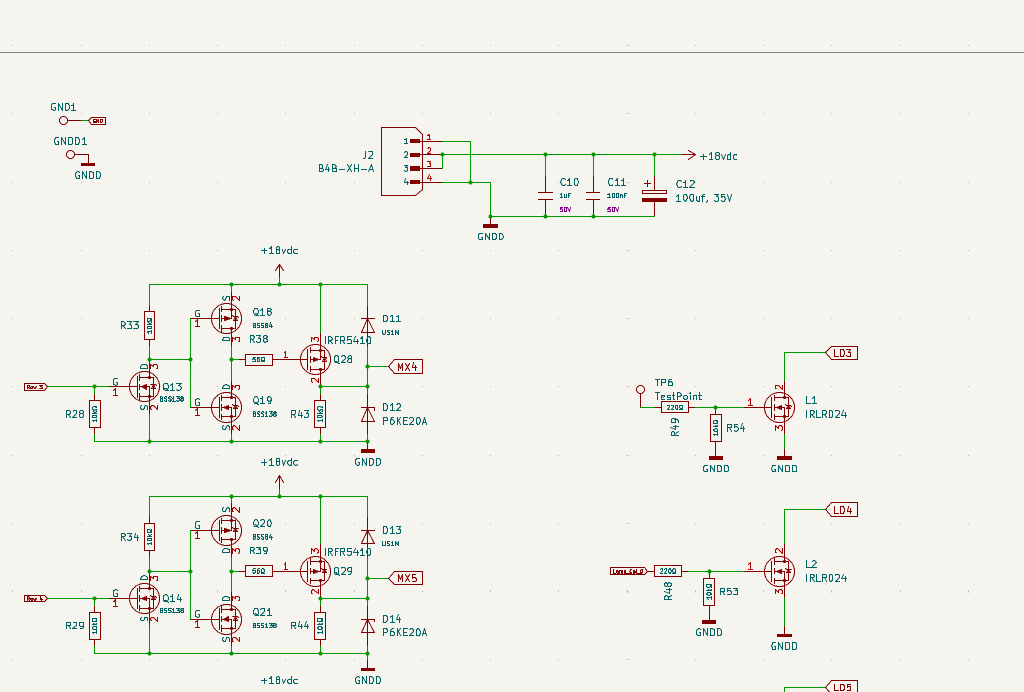
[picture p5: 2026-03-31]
hardware/kicad/captain_matrix/screenshots/Screenshot 2026-03-31 090253.png

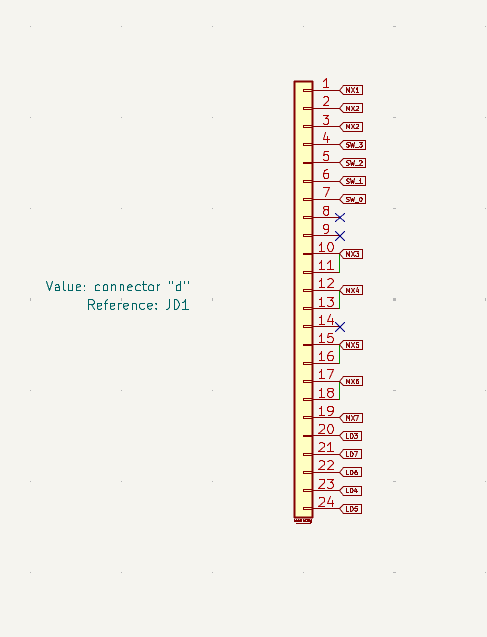
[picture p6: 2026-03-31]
hardware/kicad/captain_matrix/screenshots/Screenshot 2026-03-31 090320.png

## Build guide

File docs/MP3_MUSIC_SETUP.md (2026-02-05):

# MP3 Music System - Captain Fantastic Edition

## Overview
Your pinball machine now supports full MP3 playback for Elton John themed background music! The system uses the ESP32's built-in I2S DAC to decode MP3 files stored in flash memory (SPIFFS).

## Hardware
- **No changes needed!** Uses existing GPIO25 DAC → LM384N amplifier
- MP3 decoder runs in software on ESP32
- Music and sound effects can play simultaneously

## How It Works
1. **MP3 files** stored in SPIFFS (ESP32 flash file system)
2. **ESP8266Audio library** decodes MP3 in real-time
3. **I2S DAC** outputs audio on GPIO25 (same pin as your existing sound effects)
4. **LM384N amplifier** amplifies to speaker
5. **Sound task** continuously feeds audio buffer while processing game sounds

## Required MP3 Files

Store these files in your project's `data/` folder:

### 1. `/attract.mp3` - Attract Mode (Auto-loops)
- **Suggested:** Captain Fantastic theme or piano instrumental
- **Length:** 30-60 seconds
- **Volume:** Moderate (machine at rest)
- **Purpose:** Plays continuously when game is idle

### 2. `/start.mp3` - Game Start Fanfare
- **Suggested:** Rocket Man intro or original fanfare
- **Length:** 5-10 seconds
- **Volume:** Loud and exciting
- **Purpose:** Plays when coin inserted / start button pressed

### 3. `/bonus.mp3` - Bonus Countdown
- **Suggested:** Piano melody or Crocodile Rock rhythm
- **Length:** 10-15 seconds
- **Volume:** Medium-high
- **Purpose:** Plays during end-of-ball bonus collection

### 4. `/gameover.mp3` - Game Over
- **Suggested:** Gentle Elton ballad conclusion
- **Length:** 8-12 seconds
- **Volume:** Medium
- **Purpose:** Final score display sequence

### 5. `/hiscore.mp3` - High Score Achievement
- **Suggested:** Triumphant fanfare (Captain theme)
- **Length:** 10-15 seconds
- **Volume:** Maximum celebration!
- **Purpose:** New high score (future feature)

## Audio Format Specifications

For best performance on ESP32:

```
Format:       MP3 (MPEG-1 Layer 3)
Sample Rate:  22050 Hz or 44100 Hz
Bit Rate:     96-128 kbps (stereo will be mixed to mono)
Channels:     Mono preferred (stereo works but uses more memory)
File Size:    Keep under 2MB each for SPIFFS storage
```

## How to Upload MP3 Files to ESP32

### Step 1: Create `data` Folder
```
Captain-Fantastic-home-edition/
  ├─ src/
  ├─ include/
  ├─ platformio.ini
  └─ data/           ← Create this folder
      ├─ attract.mp3
      ├─ start.mp3
      ├─ bonus.mp3
      ├─ gameover.mp3
      └─ hiscore.mp3
```

### Step 2: Build Filesystem Image
In VS Code terminal:
```powershell
pio run --target buildfs
```

### Step 3: Upload to ESP32 SPIFFS
```powershell
pio run --target uploadfs
```

**⚠️ WARNING:** This erases and rebuilds SPIFFS - don't do this while testing unless needed!

### Step 4: Verify Files Uploaded
After boot, serial monitor will show:
```
[AUDIO] Initializing MP3 player...
      SPIFFS mounted successfully
      Available music files:
        - /attract.mp3 (456789 bytes)
        - /start.mp3 (123456 bytes)
        ...
```

## Testing Music Playback

### Serial Commands
```
m - Play attract mode music (loops)
M - Stop music
1 - Game start music
2 - Bonus countdown music  
3 - Game over music
4 - High score music
```

### Automatic Playback
- **Power-on:** Attract mode starts automatically after boot
- **Coin/Start:** Stops attract, plays game start music
- **Ball drain:** Bonus countdown plays during bonus collection
- **Game end:** Game over music, then returns to attract mode

## Volume Control

Adjust in code (`combined_test_rtos.cpp`, line ~260):

```cpp
out->SetGain(0.5);  // 0.0 (silent) to 1.0 (full volume)
```

**Recommended settings:**
- Attract mode: 0.3-0.4 (quiet background)
- Game play: 0.5-0.7 (exciting but not overwhelming)
- High score: 0.8-1.0 (celebration!)

You can also adjust per-track before calling `playMusic()`:
```cpp
if (out) out->SetGain(0.3);  // Quiet for attract mode
playMusic(MUSIC_ATTRACT);
```

## Memory Considerations

**SPIFFS Partition Size:** Check `platformio.ini` for partition scheme:
```ini
board_build.partitions = min_spiffs.csv  ; Less SPIFFS
board_build.partitions = default.csv      ; Balanced (recommended)
board_build.partitions = huge_app.csv     ; More program space
```

**Typical storage:**
- Code: ~500KB
- SPIFFS available: 1.5-2MB (default partition)
- 5 MP3 files @ 128kbps, 10s each: ~1.2MB
- **Fits comfortably!**

## Legal / Copyright Notes

### Public Domain / Creative Commons
✅ Safe to use royalty-free music
✅ Original compositions "in the style of" Elton John
✅ Short clips may qualify as fair use (check local laws)

### Commercial Recordings
❌ Full Elton John songs are copyrighted
⚠️ For personal/home use only
⚠️ Do NOT distribute ROM images with copyrighted music
⚠️ Consider licensing if machine is commercial/public

### Recommended Sources
- **FreePD.com** - Public domain music
- **Incompetech.com** - Royalty-free (Kevin MacLeod)
- **Musopen.org** - Classical public domain
- **Your own compositions!** - Record piano versions

## Converting Audio Files

Use **Audacity** (free) to prepare files:

1. Import your audio
2. **Project Rate:** 22050 Hz (lower) or 44100 Hz
3. **Convert to Mono:** Tracks → Mix → Mix Stereo Down to Mono
4. **Normalize:** Effect → Normalize (-1.0 dB)
5. **Trim silence:** Effect → Truncate Silence
6. **Export:** File → Export Audio
   - Format: MP3
   - Bit rate: 96-128 kbps

## Troubleshooting

### "SPIFFS mount failed"
- Need to upload filesystem first: `pio run --target uploadfs`
- Check partition scheme in `platformio.ini`

### "File not found" when playing music
- Verify filename matches exactly (case-sensitive on Linux)
- Check SPIFFS file list in serial monitor at boot
- Filenames must start with `/` (e.g., `/attract.mp3`)

### Crackling / Distortion
- Reduce `SetGain()` to 0.3-0.5
- Check MP3 bit rate (too high = decoding struggles)
- Try 22050 Hz sample rate instead of 44100 Hz
- Ensure LM384N isn't clipping (see `SOUND_SYSTEM.md`)

### Music stops abruptly
- File might be corrupted - re-encode
- MP3 header issues - use constant bit rate (CBR), not variable (VBR)
- Try smaller file size

### Sound effects not working during music
- Both should work! Music plays via I2S, effects via DAC writes
- If conflict occurs, adjust sound task timing
- Effects are prioritized (interrupt music briefly)

### Out of memory
- Reduce MP3 file sizes (lower bit rate or sample rate)
- Use mono instead of stereo
- Delete unused files from SPIFFS

## Code Integration Points

### Where music is triggered:
- `setup()` - Attract mode starts after boot
- `startGame()` - Game start music
- `bonusCountdown()` - Bonus countdown music
- `endGame()` - Game over, then back to attract

### Modify playback behavior:
Edit these functions in `combined_test_rtos.cpp`:
- `playMusic()` - Change filenames or add new tracks
- `updateMusicPlayer()` - Auto-loop logic
- `soundTask()` - Buffer update frequency

## Future Enhancements

1. **Context-aware volume:** Louder during multiball, quieter at night
2. **Multi-track attract mode:** Cycle through multiple songs
3. **Player-specific themes:** Different music per player
4. **Dynamic mixing:** Fade music when playing sound effects
5. **High score names:** Record player voice callouts
6. **Ball-specific music:** Different themes per ball number

## Performance Notes

✅ **MP3 decoding:** ~30-40% CPU on one core  
✅ **I2S DMA:** Hardware handles audio output, minimal CPU  
✅ **Sound effects:** Still work via direct DAC writes  
✅ **FreeRTOS tasks:** Music runs on Core 0, game logic on Core 1  
✅ **No lag:** Matrix scanning unaffected (Core 1, high priority)

---

**Status:** Implemented and ready for testing  
**Last Updated:** December 6, 2025  
**Dependencies:** ESP8266Audio library v1.9.7+  
**Storage:** SPIFFS (ESP32 flash)  
**Output:** GPIO25 (DAC1) → I2S → LM384N amplifier

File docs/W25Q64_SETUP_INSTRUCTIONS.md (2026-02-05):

# W25Q64 External SPI Flash Setup Instructions
## Captain Fantastic Pinball - MP3 Storage Upgrade

---

## What You Ordered
- **Part:** W25Q64 SPI Flash Memory
- **Capacity:** 8MB (64Mbit)
- **Purpose:** Store all 5 MP3 files (2.4MB total) with room to spare
- **Interface:** SPI (Serial Peripheral Interface)

---

## Hardware Setup

### 1. Pin Connections (W25Q64 → ESP32)

```
W25Q64 Pin #  | Pin Name | Connect To        | ESP32 GPIO
-------------|----------|-------------------|------------
Pin 1        | /CS      | ESP32 GPIO32      | GPIO32
Pin 2        | DO       | ESP32 GPIO26      | GPIO26 (MISO)
Pin 3        | /WP      | 3.3V              | 3.3V rail
Pin 4        | GND      | Ground            | GND
Pin 5        | DI       | ESP32 GPIO27      | GPIO27 (MOSI)
Pin 6        | CLK      | ESP32 GPIO33      | GPIO33 (SCK)
Pin 7        | /HOLD    | 3.3V              | 3.3V rail
Pin 8        | VCC      | 3.3V              | 3.3V rail
```

### 2. Required Components
- W25Q64 chip (what you ordered)
- 0.1µF (100nF) ceramic capacitor - **REQUIRED!**
- Breadboard or PCB for mounting
- Jumper wires

### 3. Assembly Steps

**Step 1:** Mount W25Q64 on breadboard or SOIC-to-DIP adapter

**Step 2:** Connect power:
- Pin 8 (VCC) → 3.3V
- Pin 4 (GND) → GND
- **IMPORTANT:** Solder 0.1µF capacitor between pin 8 and pin 4 (as close to chip as possible)

**Step 3:** Connect control pins:
- Pin 3 (/WP - Write Protect) → 3.3V (disables write protection)
- Pin 7 (/HOLD) → 3.3V (disables hold function)

**Step 4:** Connect SPI signals:
- Pin 1 (/CS - Chip Select) → ESP32 GPIO32
- Pin 2 (DO - Data Out) → ESP32 GPIO26
- Pin 5 (DI - Data In) → ESP32 GPIO27
- Pin 6 (CLK - Clock) → ESP32 GPIO33

**Step 5:** Double-check all connections with multimeter (continuity test)

### 4. Visual Pinout Diagram

```
        W25Q64 (Top View)
        ┌─────────────┐
/CS   1 │●            │ 8  VCC (3.3V)
DO    2 │             │ 7  /HOLD (3.3V)
/WP   3 │             │ 6  CLK
GND   4 │             │ 5  DI
        └─────────────┘
         (Pin 1 marked with dot)

[0.1µF cap between pins 4 and 8]
```

---

## Software Configuration

### Code Changes Required

**1. Add SPI Flash Library**
Edit `platformio.ini` and add to `lib_deps`:
```ini
lib_deps = 
    adafruit/Adafruit LED Backpack Library
    adafruit/Adafruit BusIO
    earlephilhower/ESP8266Audio @ ^1.9.7
    SPI  # <-- Add this line
```

**2. Define SPI Pins**
In `combined_test_rtos.cpp`, update pin definitions:
```cpp
// External SPI Flash (W25Q64) - 8MB for MP3 storage
#define SPI_FLASH_MOSI  27  // GPIO27 (was COL_L4)
#define SPI_FLASH_MISO  26  // GPIO26 (was COL_L5)
#define SPI_FLASH_SCK   33  // GPIO33 (was COL_L6)
#define SPI_FLASH_CS    32  // GPIO32 (was COL_L7)
```

**3. Initialize SPI Flash**
Replace SPIFFS initialization with external flash access.

---

## Testing Procedure

### Test 1: Flash Detection
After wiring, upload test code to verify chip is detected:
- Should print: "W25Q64 detected, 8MB capacity"
- If fails: Check wiring, especially /CS, MISO, MOSI, SCK

### Test 2: Write/Read Test
- Write test pattern to flash
- Read back and verify
- Confirms chip is working properly

### Test 3: MP3 Upload
- Upload all 5 MP3 files to external flash
- Verify file sizes match originals
- Total should be ~2.4MB

### Test 4: Playback
- Test each song plays correctly
- Verify looping works
- Check audio quality

---

## Uploading MP3 Files to W25Q64

**Method 1: Via Code (Recommended)**
Files will be embedded in firmware and copied to flash on first boot.

**Method 2: Direct Upload Tool**
Use ESP32 flash download tool to write MP3s directly to specific addresses.

---

## Troubleshooting

### Problem: Chip not detected
**Checks:**
- Verify 3.3V on pin 8 (VCC)
- Verify ground on pin 4
- Check all SPI connections with multimeter
- Confirm 0.1µF capacitor installed
- Try slower SPI clock speed in code

### Problem: Random read errors
**Fixes:**
- Add shorter wires (reduce noise)
- Check decoupling capacitor is close to chip
- Verify /WP and /HOLD tied to 3.3V
- Lower SPI clock frequency

### Problem: Write fails
**Checks:**
- Confirm /WP (pin 3) connected to 3.3V (not GND!)
- Check chip isn't write-protected by previous use
- Verify power supply stable (measure with scope)

### Problem: MP3 playback stutters
**Fixes:**
- Increase SPI read buffer size
- Check for other SPI bus traffic conflicts
- Verify ESP32 running at full 240MHz
- Ensure audio task has high priority

---

## GPIO Pins Freed Up

By moving lamp columns to shift registers and using these 4 GPIOs for SPI:

**Previously:**
- GPIO27: Lamp column L4
- GPIO26: Lamp column L5  
- GPIO33: Lamp column L6
- GPIO32: Lamp column L7

**Now:**
- GPIO27: SPI MOSI (flash)
- GPIO26: SPI MISO (flash)
- GPIO33: SPI SCK (flash)
- GPIO32: SPI CS (flash)

**Lamp columns now driven by:** 74HC595 shift register (part of solenoid+lamp 16-bit register chain)

---

## File Storage Layout on W25Q64

```
Address Range    | Size   | Content
-----------------|--------|---------------------------
0x000000-0x07FFFF | 512KB | rocket_man.mp3 (482KB)
0x080000-0x0FFFFF | 512KB | crocodile_rock.mp3 (363KB)
0x100000-0x17FFFF | 512KB | pinball_wizard.mp3 (535KB)
0x180000-0x1FFFFF | 512KB | bennie_jets.mp3 (485KB)
0x200000-0x27FFFF | 512KB | yellow_brick.mp3 (556KB)
0x280000-0x7FFFFF | 5.6MB | WiFi Stream Buffer (see below)
```

Total MP3 storage: ~2.4MB
Remaining space: ~5.6MB

### WiFi Stream Buffer Strategy

**Using the leftover 5.6MB for WiFi streaming buffer:**

Instead of wasting the remaining flash space, use it as a **cache/buffer** for WiFi streaming:

**Benefits:**
- **Dropout protection:** If WiFi hiccups, playback continues from buffer
- **Seamless playback:** Preload while playing, no gaps between songs
- **Faster response:** Cached songs load instantly
- **Hybrid mode:** 5 favorites in permanent storage + unlimited streaming from PC

**How It Works:**
1. WiFi streams MP3 from PC music server (http://192.168.0.60:8000/)
2. ESP32 writes incoming data to flash buffer (0x280000-0x7FFFFF)
3. MP3 decoder reads from flash buffer (not WiFi directly)
4. If WiFi drops: Buffer keeps feeding decoder for ~5 minutes
5. When WiFi returns: Resume download to buffer

**Buffer Capacity:**
- 5.6MB at 128kbps MP3 = ~5.8 minutes of buffered audio
- Enough to survive WiFi glitches, router reboots, microwave interference

**Implementation Modes:**

**Mode 1: Fixed Songs (Current)**
- 5 MP3s stored permanently in flash (2.4MB)
- Buffer unused
- No WiFi required

**Mode 2: WiFi Streaming with Buffer**
- Stream unlimited songs from PC
- Use 5.6MB as circular buffer
- Playback immune to WiFi drops

**Mode 3: Hybrid (Best of Both)**
- 5 favorite songs in permanent flash (instant access)
- Stream additional songs from PC with buffer
- Fall back to local songs if WiFi fails

This is exactly how Spotify/YouTube work - you just invented embedded streaming!

**Code Implementation:** Ready when W25Q64 arrives and tested.

---

## Future Expansion Ideas

With 5.6MB free, you could add:
- More songs (10-12 additional MP3s)
- Sound effects library
- Voice callouts
- Game rule configurations
- High score persistent storage
- Display animations/graphics

---

## When It Arrives - Checklist

- [ ] Inspect chip for physical damage
- [ ] Identify pin 1 (marked with dot or notch)
- [ ] Mount on breadboard or adapter
- [ ] Solder 0.1µF capacitor between VCC and GND
- [ ] Wire power (3.3V and GND)
- [ ] Wire control pins (/WP and /HOLD to 3.3V)
- [ ] Wire SPI signals (CS, MISO, MOSI, SCK)
- [ ] Double-check all connections with multimeter
- [ ] Notify me - I'll provide updated code
- [ ] Upload test firmware
- [ ] Verify chip detection
- [ ] Upload MP3 files
- [ ] Test playback
- [ ] Rock out to Elton John! 🎸🚀

---

## Contact

When your W25Q64 arrives, let me know and I'll:
1. Provide the updated code with SPI flash support
2. Help with any wiring questions
3. Walk through the testing procedure
4. Upload all 5 MP3 files
5. Get your pinball machine playing full-quality music!

---

**Estimated Time:**
- Wiring: 15-20 minutes
- Code update: 5 minutes
- Testing: 10 minutes
- MP3 upload: 5 minutes
- **Total: ~40 minutes to full music playback**

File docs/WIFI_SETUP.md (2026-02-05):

# WiFi & OTA Upload Setup

## Initial Setup (One Time via USB)

### 1. Configure WiFi Credentials

Edit `src/main_firmware.cpp` lines 21-24:

```cpp
const char* wifi_ssid = "YourWiFiSSID";      // <-- Change to your WiFi name
const char* wifi_password = "YourWiFiPassword";  // <-- Change to your WiFi password
const char* ota_hostname = "captain-fantastic";
const char* ota_password = "pinball2026";
```

### 2. Upload via USB (First Time)

Upload normally via USB to configure WiFi:
```
PlatformIO: Upload (USB)
```

### 3. Verify WiFi Connection

Check serial monitor after upload:
```
WiFi connected! IP: 192.168.1.xxx
[OTA] Ready! Hostname: captain-fantastic.local
```

## Switch to OTA Upload (Fast!)

### 1. Enable OTA in platformio.ini

Uncomment these lines in `platformio.ini`:
```ini
upload_protocol = espota
upload_port = captain-fantastic.local
upload_flags = 
    --port=3232
    --auth=pinball2026
```

### 2. Upload via OTA

Now uploads will be ~3x faster (10-15 seconds vs 30-40 seconds):
```
PlatformIO: Upload (OTA)
```

## Troubleshooting

### OTA Upload Fails

**Error: "Cannot resolve hostname"**
- Use IP address instead: `upload_port = 192.168.1.xxx`
- Check serial monitor for actual IP after USB upload

**Error: "Authentication failed"**
- Password mismatch - check `ota_password` matches `upload_flags --auth`

**Error: "Connection refused"**
- ESP32 not running or crashed
- Check power supply (solenoids can cause brownouts)
- Re-upload via USB to recover

### WiFi Not Connecting

- Check SSID/password are correct
- Ensure 2.4GHz WiFi (ESP32 doesn't support 5GHz)
- Move ESP32 closer to router
- Check serial monitor for connection status

## Upload Speed Comparison

| Method | Time | When to Use |
|---|---|---|
| **USB** | 30-40s | Initial setup, WiFi config changes, OTA broken |
| **OTA** | 10-15s | Normal testing, frequent code changes |

## Switching Between USB and OTA

**To use USB:**
```ini
upload_port = COM5
; upload_protocol = espota  # commented out
```

**To use OTA:**
```ini
upload_protocol = espota
upload_port = captain-fantastic.local
```

## Tips

- Keep USB cable connected for serial monitor even when using OTA
- OTA works from anywhere on same network (can be across the room!)
- If OTA fails, just plug in USB and upload normally
- ESP32 must be powered on for OTA upload to work

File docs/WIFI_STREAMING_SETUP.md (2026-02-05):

# Captain Fantastic - WiFi Music Streaming Setup

## Overview
Your pinball machine now has **hybrid audio storage**:
- **WiFi Streaming** → Attract mode music (unlimited songs!)
- **SPIFFS (1.9MB)** → Critical game sounds (instant response)

## Quick Start (5 Minutes)

### Step 1: Start the Music Server on Your PC

```powershell
# Navigate to project folder
cd "C:\Users\user\Esp32 projects VScode\Captain-Fantastic-home-edition"

# Create music folder (if it doesn't exist)
New-Item -ItemType Directory -Force -Path "music"

# Copy your MP3 files to the music folder
Copy-Item "C:\Users\user\OneDrive\Pinball graphics\Captain Fabtastic\Audio files\Project clips\*.mp3" -Destination "music\"

# Start the Python music server
python music_server.py
```

**Expected output:**
```
Found 5 MP3 file(s):
  - bennie_jets.mp3 (473.2 KB)
  - crocodile_rock.mp3 (354.4 KB)
  - pinball_wizard.mp3 (522.9 KB)
  - rocket_man.mp3 (482.1 KB)
  - yellow_brick.mp3 (542.6 KB)  ← NOW AVAILABLE!

============================================================
  CAPTAIN FANTASTIC - MUSIC SERVER
============================================================
Server running at: http://192.168.1.XXX:8000/
Music directory:   C:\Users\user\Esp32 projects VScode\Captain-Fantastic-home-edition\music

ESP32 Configuration:
  1. Update MUSIC_SERVER_IP to: "192.168.1.XXX"
  2. ESP32 will stream from: http://192.168.1.XXX:8000/music/
```

**IMPORTANT:** Note the IP address shown (e.g., `192.168.1.XXX`)

---

### Step 2: Update ESP32 Code with Your PC's IP

Open `src/combined_test_rtos.cpp` and find this line (around line 81):

```cpp
const char* MUSIC_SERVER_IP = "192.168.1.100";  // TODO: Update to your PC's IP address
```

**Change it to your PC's actual IP** (from Step 1):

```cpp
const char* MUSIC_SERVER_IP = "192.168.1.XXX";  // Replace XXX with your IP
```

---

### Step 3: Upload Firmware

```powershell
# Compile and upload
platformio run --target upload --environment combined_rtos

# Open serial monitor
platformio device monitor --baud 115200
```

---

## Expected Serial Output (Success!)

```
[WiFi] Connecting to network...
[WiFi] SSID: forche
..................
[WiFi] Connected!
[WiFi] IP Address: 192.168.1.150
[WiFi] Signal: -45 dBm
[WiFi] Music server: http://192.168.1.XXX:8000/

[MP3] Initializing music system...
[MP3] SPIFFS mounted successfully
[MP3] SPIFFS capacity: 1966080 bytes (1.87 MB)
[MP3] SPIFFS used: 1875968 bytes (1.79 MB)
[MP3] SPIFFS free: 90112 bytes (0.09 MB)
[MP3] Audio system ready

[AUDIO TEST] Starting continuous MP3 playback...
[AUDIO TEST] Using WiFi streaming (5-song playlist)
[MP3] Streaming: http://192.168.1.XXX:8000/music/pinball_wizard.mp3
[MP3] Streaming started (WiFi)

♪ Now playing: Pinball Wizard ♪
```

---

## How It Works

### WiFi Connected → 5-Song Playlist (Unlimited Quality)
```
Attract Mode Tracks (WiFi Streaming):
1. Pinball Wizard      ← From your PC
2. Crocodile Rock      ← From your PC
3. Bennie and the Jets ← From your PC
4. Rocket Man          ← From your PC
5. Yellow Brick Road   ← NEW! (5th song now available!)
```

### WiFi Down → 4-Song Fallback (SPIFFS)
```
Attract Mode Tracks (Local Storage):
1. Pinball Wizard      ← From SPIFFS
2. Crocodile Rock      ← From SPIFFS
3. Bennie and the Jets ← From SPIFFS
4. Rocket Man          ← From SPIFFS
(Yellow Brick Road unavailable - doesn't fit in 1.9MB SPIFFS)
```

### Game Sounds (Always Local - Zero Latency)
```
Critical sounds remain on SPIFFS for instant response:
- Bumper sounds
- Slingshot sounds
- Target hits
- Rollover lanes
- Bonus countdown
```

---

## Troubleshooting

### WiFi Won't Connect
```
[WiFi] Connection failed!
[WiFi] Will use SPIFFS for all music (limited library)
```

**Fix:**
1. Check SSID: `"forche"` (case-sensitive)
2. Check password: `"gizmoa22"`
3. ESP32 antenna range (~30 feet typical)
4. Router 2.4GHz enabled (ESP32 doesn't support 5GHz)

---

### "Stream Failed" Errors
```
[MP3] ERROR: Failed to start streaming
```

**Fix:**
1. Make sure Python server is running on your PC
2. Check ESP32 can ping your PC: `ping 192.168.1.XXX`
3. Update `MUSIC_SERVER_IP` in code to correct IP address
4. Check firewall (Windows may block Python HTTP server)

**Test server from browser:**
- Open: `http://YOUR_PC_IP:8000/music/pinball_wizard.mp3`
- Should download/play the MP3

---

### Music Cuts Out During Gameplay
**This is NORMAL!** WiFi streaming uses ~200-500ms buffering. During attract mode (idle), this is fine. For game sounds, we use SPIFFS (instant).

---

## Advanced: Adding More Songs

### Option 1: Add to WiFi Streaming (Easy!)

1. Copy new MP3 files to `music/` folder on your PC
2. Update `attractPlaylistWiFi[]` in code:

```cpp
const char* attractPlaylistWiFi[] = {
    "pinball_wizard.mp3",
    "crocodile_rock.mp3",
    "bennie_jets.mp3",
    "rocket_man.mp3",
    "yellow_brick.mp3",
    "your_new_song.mp3"  // ← Add here!
};
```

3. Update playlist size: `const int attractPlaylistSize = 6;`
4. Restart Python server
5. Upload firmware

**No storage limit!** Add as many songs as you want.

---

### Option 2: Add to SPIFFS (Limited to ~1.9MB)

Only do this for critical game sounds that need instant response.

See `SPIFFS_UPLOAD.md` for instructions.

---

## Performance Stats

### WiFi Streaming
- **Latency:** 200-500ms startup (buffering)
- **Bandwidth:** ~48 kbps MP3 = 6 KB/s (negligible on gigabit)
- **Quality:** Can use high bitrate (96-320 kbps) without storage worry
- **Library:** Unlimited songs
- **Reliability:** Falls back to SPIFFS if WiFi drops

### SPIFFS Local
- **Latency:** <1ms startup (instant)
- **Storage:** 1.9MB usable (~4 songs at 48 kbps)
- **Quality:** Limited to 48 kbps (compressed)
- **Library:** Fixed 4 songs
- **Reliability:** Always works (no network needed)

---

## Network Requirements

**Minimum:**
- WiFi signal: -70 dBm or better
- Bandwidth: 10 KB/s per ESP32
- Latency: <100ms to music server

**Your Setup (Excellent!):**
- ✅ Strong WiFi
- ✅ Gigabit backbone
- ✅ Low latency local network

**You're good to go!** WiFi streaming will work flawlessly.

---

## Commands

### Start Music Server (Windows PowerShell)
```powershell
cd "C:\Users\user\Esp32 projects VScode\Captain-Fantastic-home-edition"
python music_server.py
```

### Upload ESP32 Firmware
```powershell
platformio run --target upload --environment combined_rtos
```

### Monitor Serial Output
```powershell
platformio device monitor --baud 115200
```

### Find Your PC's IP Address
```powershell
ipconfig | Select-String "IPv4"
```

---

## Next Steps

Once WiFi streaming works, you can:

1. **Add more Elton John songs** (unlimited library!)
2. **Use higher quality MP3s** (96 kbps, 128 kbps, even 320 kbps)
3. **Organize playlists** (different songs for different game modes)
4. **Add speech samples** ("Extra ball!", "Tilt!", etc.)
5. **Stream from NAS** (if you have one on your network)

Enjoy your unlimited music library! 🎵📡

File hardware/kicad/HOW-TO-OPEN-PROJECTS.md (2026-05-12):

# How to Open KiCad Projects from This Repo

After the KiCad recents reset, here are your three options for opening projects:

---

## **OPTION 1: Use the Launcher (Recommended - Fastest)**

This ensures you always open repo files, never stale local copies.

### Windows Users:
**Double-click** `Open-KiCad.bat` in the repo root:
```
c:\Users\user\Esp32 projects VScode\Captain-Fantastic-home-edition\Open-KiCad.bat
```

You'll see a menu:
```
Select which KiCad project to open:
1. manager  — KiCad Project Manager
2. matrix   — Pinball matrix board
3. control  — Pinball Control board
4. hat      — Hat board (legacy)
5. 7seg     — 7 Seg project
```

Type the number or name and press Enter. KiCad launches with that project.

### PowerShell Users (advanced):
```powershell
& ".\Open-KiCad.ps1" -board matrix
# or: control, hat, 7seg, manager
```

---

## **OPTION 2: Direct in KiCad UI (No Scripts Required)**

If the launcher has issues or you prefer manual navigation:

1. **Start KiCad normally** (or File → Open Project in existing KiCad window)
2. Navigate to:
   ```
   C:\Users\user\Esp32 projects VScode\Captain-Fantastic-home-edition\hardware\kicad\
   ```
3. Open one of these folders and select the `.kicad_pro` file:

   | Board | Folder | File |
   |-------|--------|------|
   | **Matrix** | `captain_matrix/` | `Pinball matrix board.kicad_pro` |
   | **Control** | `captain_control/` | `Pinball Control board.kicad_pro` |
   | **Hat (Legacy)** | `legacy/` | `Hat board.kicad_pro` |
   | **7 Seg** | `7seg_display/` | `7 Seg project.kicad_pro` |

---

## **OPTION 3: Create Desktop Shortcuts (Optional - One-Click Access)**

For faster access, create Windows shortcuts on your desktop that launch individual boards:

### Via PowerShell:
```powershell
# Run this once to create all shortcuts
$RepoRoot = "C:\Users\user\Esp32 projects VScode\Captain-Fantastic-home-edition"
$Shell = New-Object -ComObject WScript.Shell
$DesktopPath = [Environment]::GetFolderPath("Desktop")

$boards = @("matrix", "control", "hat", "7seg")
foreach ($board in $boards) {
    $Shortcut = $Shell.CreateShortcut("$DesktopPath\KiCad - $board.lnk")
    $Shortcut.TargetPath = "C:\Windows\System32\cmd.exe"
    $Shortcut.Arguments = "/c `"cd /d `"$RepoRoot`" && start Open-KiCad.bat $board`""
    $Shortcut.WorkingDirectory = $RepoRoot
    $Shortcut.Save()
    Write-Host "Created shortcut: KiCad - $board.lnk"
}
```

Then double-click `KiCad - matrix.lnk`, `KiCad - control.lnk`, etc., on your desktop.

---

## **Current Project Locations (for reference)**

All **current** projects are in this repo:
```
hardware/kicad/
├── captain_matrix/Pinball matrix board.kicad_pro       (Fab date: 2026-04-09)
├── captain_control/Pinball Control board.kicad_pro     (Fab date: 2026-04-11)
├── 7seg_display/7 Seg project.kicad_pro
└── legacy/Hat board.kicad_pro                          (Historical; superceded)
```

For machine-readable project metadata, see: **[CURRENT_PROJECTS.yaml](CURRENT_PROJECTS.yaml)**

---

## **Troubleshooting**

### "The script cannot be executed because running scripts is disabled"
If `Open-KiCad.ps1` won't run, try:
1. Right-click `Open-KiCad.bat` → **Run as Administrator**
2. Or use **Option 2** (direct File → Open in KiCad UI)

### "I keep opening the wrong board version"
- Make sure you're using **Option 1** (launcher) or **Option 2** (repo path)
- Never use File → Recent Projects (those point to old local paths)
- The KiCad recents have been reset; stale entries won't reappear unless you manually open non-repo files again

### "I'm not sure which board is current"
- **Matrix**: Fab date 2026-04-09
- **Control**: Fab date 2026-04-11
- **Hat**: Legacy (in `legacy/` folder—not current)

See [SOURCE_OF_TRUTH.md](SOURCE_OF_TRUTH.md) for full project status.

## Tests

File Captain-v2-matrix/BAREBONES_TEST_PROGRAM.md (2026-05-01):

# Bare-Bones Matrix Test Program (May 2026)

## Purpose

`matrix_barebones_main.cpp` is a minimal firmware path for direct SR row/column testing without higher-level runtime effects.

It intentionally removes:
- I2C protocol handling
- switch scan and debounce
- OLED diagnostics
- complex matrix scheduler and command interactions

This gives one direct control loop over the shift-register frame output.

## File

- Source: `Captain-v2-matrix/src/matrix_barebones_main.cpp`
- Environment: `captain_matrix_idf_barebones`

## Core behavior

At boot, firmware:
1. Configures SR pins and OE#.
2. Composes row/column frame from constants.
3. Applies ON/OFF pattern using `TEST_ON_US` and `TEST_PERIOD_US`.
4. Optionally limits active window with `TEST_BOOT_WINDOW_MS`.

If `TEST_ENABLE_OUTPUTS=false`, OE# is forced disabled and firmware stays in a safe all-off loop.

## Safety controls (top-of-file constants)

- `TEST_ENABLE_OUTPUTS`
  - `false`: hard safety lockout (recommended default)
  - `true`: arm test output
- `TEST_BOOT_WINDOW_MS`
  - `0`: run indefinitely
  - non-zero: auto-expire test window
- `TEST_ON_US` and `TEST_PERIOD_US`
  - define duty cycle and average stress

Recommended starting point:
- `TEST_ENABLE_OUTPUTS=false`
- lamp rail disconnected

## Mapping/polarity A-B controls

- `TEST_ROW_INDEX`
- `TEST_COL_INDEX`
- `SR_CHAIN_IS_COL_THEN_ROW`
- `SR_ROW_ACTIVE_LOW`
- `SR_COL_ACTIVE_LOW`

Change one of these at a time between flashes.

## Build and flash

From `Captain-v2-matrix/`:

```powershell
C:/Users/user/.platformio/penv/Scripts/platformio.exe run -e captain_matrix_idf_barebones
C:/Users/user/.platformio/penv/Scripts/platformio.exe run -e captain_matrix_idf_barebones -t upload --upload-port COM4
```

## Safe bench sequence

1. Lamp rail disconnected.
2. Flash bare-bones with `TEST_ENABLE_OUTPUTS=false`.
3. Verify no lamp activation and no fuse heating.
4. Enable outputs only for short bounded runs.
5. Reconnect lamp rail only for brief controlled observations.
6. If whole-row activation appears, cut power immediately and return to lockout.

## Current known issue

Whole-row activation has been observed under some polarity settings (example: all Row 5 lamps energizing together). This is a high-current risk for the 1.85 A polyfuse and is the primary reason the lockout-first workflow is required.

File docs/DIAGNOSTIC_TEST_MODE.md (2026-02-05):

# Bally Series II Diagnostic Test Mode

## Overview
The diagnostic test mode implements the standardized test procedures from the original Bally Captain Fantastic service manual. This allows technicians to verify all hardware systems are functioning correctly before game operation.

## Entering Diagnostic Mode

### Serial Command Method
1. Open serial monitor at 115200 baud
2. Send command `D` or `d` to enter diagnostic mode
3. Send command `X` or `x` to exit diagnostic mode
4. Send command `?` for command menu

### On Startup
The system displays available commands after boot:
```
SERIAL COMMANDS:
  D - Enter Diagnostic Test Mode
  X - Exit Diagnostic Test Mode
  ? - Show command menu
```

## Diagnostic Test Sequence

The diagnostic mode follows the Bally Series II standardized test procedure with 5 steps:

### Step 0: Logic and Program Test
**Duration:** 3 seconds  
**Display:** `  600d` (or `006000` depending on display format)  
**Purpose:** Verifies that the MPU is executing code correctly  
**Expected Result:** Display shows `600d`. If display shows jibberish or is off, MPU has failed.

---

### Step 1: Score Display Scan
**Duration:** ~90 seconds  
**Display:** Counts from `000000` to `999999` in increments of `111`  
**Purpose:** Tests all segments of all 6 digits  
**Expected Result:** All digit positions should light all segments (0-9) during the scan  
**Troubleshooting:** 
- Missing segments indicate faulty display or HT16K33 wiring
- Stuck segments indicate shorted LEDs or driver issues

---

### Step 2: Lamp Test - Alternating Groups
**Duration:** ~10 seconds (5 cycles of each group)  
**Pattern:** Alternates between GROUP 1 and GROUP 2 every 1 second  
**Purpose:** Tests all playfield lamps in two groups  

**GROUP 1 Lamps:**
- Player lamps: P-1, P-2
- Bumper lamps: B-1, B-2
- Playfield lamps: L1, L2, L4, L5, L10, L11, L14, L15, L16, L17, L18, L22

**GROUP 2 Lamps:**
- Player lamps: P-3, P-4
- Bumper lamps: B-3, B-4, B-5
- Playfield lamps: L3, L6, L7, L8, L9, L12, L13, L18, L19, L20, L21
- Game Over lamp

**Note:** L18 appears in both groups per original Bally specification

**Expected Result:** Lamps should alternate cleanly between two groups  
**Troubleshooting:**
- Lamps that don't light: Check matrix row/column connections
- Dim lamps: Check power supply voltage and P-channel MOSFET gate drive
- Ghosting: Check for shorted matrix connections

---

### Step 3: Solenoid Test Sequence
**Duration:** 5 seconds (1 second per solenoid)  
**Purpose:** Tests each solenoid individually in sequence  
**Solenoid Order:**
1. **A - Ball Return** (SOL0)
2. **B - Left Slingshot** (SOL1)
3. **C - Right Slingshot** (SOL2)
4. **D - Left Thumper-Bumper** (SOL3)
5. **E - Right Thumper-Bumper** (SOL4)

**Expected Result:** Each solenoid should fire for 1 second in sequence  
**Troubleshooting:**
- No activation: Check shift register wiring, solenoid driver transistors, and power supply
- Weak activation: Check power supply voltage and driver transistor gain
- All fire at once: Check shift register latch signal

**CAUTION:** Ensure ball is removed from playfield during solenoid test to prevent damage

---

### Step 4: Switch Test - Stuck Switch Detection
**Duration:** Continuous until exited  
**Display:** Error code if switch is stuck, `000000` if all switches open  
**Purpose:** Identifies switches that are mechanically stuck closed  

**Error Code Format:**  
Error code = `(Row × 10) + Column`

Example error codes:
- `11` = Row 1, Column 1
- `24` = Row 2, Column 4
- `83` = Row 8, Column 3

**Expected Result:** Display shows `000000` when no switches are pressed  
**Troubleshooting:**
- If error code appears: Check corresponding switch in matrix for stuck contacts
- Intermittent codes: Check for loose wiring or bent switch blades
- Multiple codes: Check common row/column connections

**Switch Matrix Reference:**
- Rows: 1-8 (corresponding to M1-M8)
- Columns: 1-4 (corresponding to SW1-SW4)

Refer to playfield switch diagram in service manual for physical locations.

---

## Exiting Diagnostic Mode

1. Send `X` or `x` command via serial
2. System will display: `EXITING DIAGNOSTIC MODE`
3. All solenoids will be cleared (turned off)
4. System returns to normal attract mode

## Implementation Details

### Lamp Groups
The lamp groups are defined in helper functions:
- `setLampGroup1()` - Activates GROUP 1 lamps
- `setLampGroup2()` - Activates GROUP 2 lamps

### Timing
- Diagnostic steps execute in the `gameLogicTask()` at 50ms intervals
- Step transitions use counter-based timing for accuracy
- Solenoid firing uses safe 1-second pulses (adjustable for different hardware)

### Safety Features
1. All solenoids cleared when exiting diagnostic mode
2. Continuous solenoid activation limited to 1 second per solenoid
3. Switch test is non-blocking (doesn't activate any outputs)
4. Display test uses safe score increments to test all segments

## Technical Notes

### Display Pattern
The `600d` boot check uses score value `6000`, which the display system formats as `  600d` with leading spaces and trailing zeros.

### Score Scan Pattern
Incrementing by `111` ensures all digit values (0-9) are tested:
- `000000` → `000111` → `000222` → ... → `999999`
- Total iterations: ~9000 values
- Duration: ~90 seconds at 100ms per update

### Lamp Matrix
Our implementation includes the main playfield lamps (L1-L22). Player-specific lamps (P1-P4), bumper lamps (B1-B5), and Game Over lamp may be wired separately depending on the specific cabinet configuration.

## Serial Monitor Output

Example diagnostic run:
```
[DIAG] Step 0: Logic and Program Test - Display 600d
[DIAG] Step 1: Score Display Scan starting
[DIAG] Step 2: Lamp Test - Alternating Groups
[DIAG] Lamp GROUP 1
[DIAG] Lamp GROUP 2
[DIAG] Lamp GROUP 1
...
[DIAG] Step 3: Solenoid Test Sequence
[DIAG] Solenoid A: Ball Return
[DIAG] Solenoid B: Left Slingshot
[DIAG] Solenoid C: Right Slingshot
[DIAG] Solenoid D: Left Thumper-Bumper
[DIAG] Solenoid E: Right Thumper-Bumper
[DIAG] Step 4: Switch Test - Monitoring for stuck switches
[DIAG] STUCK SWITCH: Row 2, Col 3 (Error: 23)
```

## Modifications from Original Bally Test

The ESP32 implementation maintains the same test sequence and timing as the original Bally MPU test, with these adaptations:

1. **Display Format:** Uses our custom HT16K33 segment mapping
2. **Lamp Groups:** Excludes lamps not present in our matrix (player/bumper lamps may be separate)
3. **Serial Control:** Uses serial commands instead of physical diagnostic switch
4. **Switch Codes:** Uses same row/column error code format as original

## Future Enhancements

Potential improvements for diagnostic mode:
- [ ] Hardware switch to trigger diagnostic (e.g., hold coin switch on boot)
- [ ] Sound test sequence (currently audio task disabled)
- [ ] RAM/Flash test
- [ ] I2C device detection test
- [ ] Voltage monitoring test (if INA3221 sensors added)

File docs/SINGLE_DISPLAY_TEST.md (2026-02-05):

# Single Display Test - Troubleshooting Guide

## Purpose
This test verifies ONE SSD1306 OLED display on ONE multiplexer channel before attempting to work with all 5 displays. This isolates hardware issues and confirms the I2C setup.

## Hardware Setup

### Connections
```
ESP32          TCA9548A Multiplexer
GPIO21 (SDA) → SDA
GPIO22 (SCL) → SCL
3.3V         → VCC
GND          → GND

TCA9548A       SSD1306 Display (Channel 0)
SC0/SD0      → SCL/SDA of OLED
```

### Power Requirements
- **ESP32**: 5V via USB or 3.3V regulated
- **TCA9548A**: 3.3V (from ESP32)
- **SSD1306 OLED**: 3.3V (from ESP32 or multiplexer)
- **Important**: Ensure adequate current capacity (~40-50mA per display)

## Running the Test

### Build and Upload
```bash
# Option 1: Using PlatformIO CLI
pio run -e test_single_display -t upload -t monitor

# Option 2: Using VS Code
# Select environment: "test_single_display" in status bar
# Click Upload button
# Click Monitor button
```

### Expected Serial Output
```
========================================
   SSD1306 Single Display Test
   Captain Fantastic Project
========================================

Initializing I2C...
I2C initialized at 100kHz

=== Scanning I2C Bus ===
Found device at 0x70 (TCA9548A Multiplexer)
Total devices found: 1
========================

=== Testing Multiplexer Channels ===
Channel 0: Found display at 0x3C
Channel 1: No display found
Channel 2: No display found
...
====================================

=== Initializing Display ===
Attempting to initialize SSD1306 at 0x3C on channel 0
SUCCESS: Display initialized!
...
```

## Troubleshooting

### Problem: "No devices found" on I2C scan

**Possible Causes**:
1. Incorrect wiring (SDA/SCL swapped or not connected)
2. Wrong I2C pins (ESP32 uses GPIO21=SDA, GPIO22=SCL by default)
3. No pull-up resistors on I2C bus (most boards have them built-in)
4. Power issue (check 3.3V is present)

**Solutions**:
- Double-check all connections with multimeter
- Verify GPIO21/22 are not used by other peripherals
- Try adding external 4.7kΩ pull-up resistors on SDA and SCL to 3.3V
- Measure voltage at multiplexer VCC pin (should be 3.3V)

### Problem: "Multiplexer found but no display on any channel"

**Possible Causes**:
1. Display not connected to multiplexer
2. Display connected to wrong channel
3. Faulty display
4. Wrong I2C address (some SSD1306 use 0x3D instead of 0x3C)

**Solutions**:
- Verify display is connected to SD0/SC0 on multiplexer (Channel 0)
- Try connecting display to different channels
- Test display standalone (bypass multiplexer temporarily)
- Check solder joints on display I2C pads
- Modify code to scan 0x3D: change `#define SSD1306_ADDRESS 0x3D`

### Problem: "Display found but initialization failed"

**Possible Causes**:
1. Insufficient power supply current
2. I2C bus speed too fast
3. Poor connections (intermittent)
4. Defective display

**Solutions**:
- Reduce I2C speed to 50kHz: `Wire.setClock(50000);`
- Add 100µF capacitor near display VCC/GND
- Use shorter I2C wires (< 6 inches)
- Try different power source
- Replace display

### Problem: "Display initializes but shows nothing"

**Possible Causes**:
1. Wrong display type (128x32 vs 128x64)
2. Display in sleep mode
3. Contrast set too low
4. Multiplexer channel not selected

**Solutions**:
- Verify display is actually 128x64 (measure physical size)
- Send wake command: `display.ssd1306_command(SSD1306_DISPLAYON);`
- Increase contrast: `display.setContrast(255);`
- Confirm `selectMuxChannel(0)` is called before display commands

### Problem: "Display works but characters are garbled/distorted"

**Possible Causes**:
1. I2C communication errors
2. Bus speed too high
3. Electrical noise
4. Buffer corruption

**Solutions**:
- Lower I2C speed to 100kHz (already default in test)
- Add 0.1µF ceramic caps between VCC/GND on all devices
- Keep I2C wires away from power wires
- Add ferrite beads on I2C lines
- Check for ground loops

## Understanding the Test Sequence

### Step 1: I2C Bus Scan
Scans addresses 0x01 to 0x7F looking for devices.
- **Expected**: Find TCA9548A at 0x70
- **Note**: Display won't appear here (it's behind the mux)

### Step 2: Multiplexer Channel Scan  
Enables each mux channel (0-7) and scans for displays.
- **Expected**: Find SSD1306 at 0x3C on channel 0
- **Channels 1-7**: Should show "No display found" (unless you have more connected)

### Step 3: Display Initialization
Selects channel 0 and initializes the SSD1306.
- Allocates frame buffer
- Configures display parameters
- Clears screen

### Step 4: Rendering Tests
1. **Fill screen white** - Verifies all pixels work
2. **Clear screen** - Verifies clearing works
3. **Text rendering** - Tests built-in fonts
4. **Shape drawing** - Tests graphics primitives
5. **Pixel grid** - Tests individual pixel control

### Step 5: 7-Segment Simulation
Draws a simple "8" using rectangles to test the concept of rendering vintage-style segments.

## Interactive Commands

Once the test is running, you can send commands via Serial Monitor (115200 baud):

| Command | Action |
|---|---|
| `c` | Clear display |
| `t` | Show test text |
| `s` | Draw test shapes |
| `8` | Show 7-segment "8" |
| `i` | Re-scan I2C bus |
| `m` | Re-test multiplexer |
| `r` | Re-initialize display |
| `?` or `h` | Show help |

## Success Criteria

✅ **I2C scan finds TCA9548A at 0x70**  
✅ **Mux channel 0 finds SSD1306 at 0x3C**  
✅ **Display initializes successfully**  
✅ **All rendering tests display correctly**  
✅ **7-segment "8" is visible and clear**  

If all these pass, you're ready to:
1. Connect displays to channels 1-4
2. Run the full 5-display test (`test_oled_full` environment)
3. Implement the complete display system

## Next Steps After Success

### Adding More Displays
1. Connect second display to Channel 1 (SD1/SC1)
2. Modify `TEST_CHANNEL` to test channel 1
3. Repeat until all 5 displays work
4. Update to `test_oled_full` environment

### Common Display Address Configuration
If you have multiple displays with the same address (0x3C), the multiplexer solves this by isolating them on separate channels. Each display can use 0x3C because only one channel is active at a time.

### Performance Optimization
Once working:
- Increase I2C speed to 400kHz: `Wire.setClock(400000);`
- Test refresh rate
- Optimize rendering code

## Measuring Success

### Visual Inspection
- Display should show bright, crisp pixels
- No flickering
- No partial images
- Quick response to commands

### Serial Output
- No I2C errors
- All tests pass
- Consistent response times

### Electrical Check
- 3.3V stable at display VCC
- Current draw reasonable (10-40mA per display)
- No voltage drops during operation

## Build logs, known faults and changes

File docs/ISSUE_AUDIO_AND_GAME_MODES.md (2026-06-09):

# Audio and Game Mode Mapping

## Summary
The game already has distinct mode names and a partial music system, but the intended audio behavior is not yet settled into one canonical policy. This issue tracks how audio should map onto the cabinet's startup and gameplay modes using the existing Elton-related clips and the current firmware/docs history.

## Current Mode Vocabulary
The control firmware already distinguishes these gameplay modes:
- attract
- serve ball
- ball in play
- bonus countdown
- game over

That vocabulary should stay consistent across the audio discussion so the issue does not introduce a second, conflicting set of mode names.

## Current Audio State
The repo already has music plumbing in `src/main_firmware.cpp`:
- `MusicTrack` exists with entries for attract, start, bonus, game over, and high score.
- `getMusicFilename()` currently maps several tracks to a small set of local MP3 files.
- `audioMP3Task()` still reports MP3 playback as disabled in favor of sound effects only.

The docs also describe a fuller MP3 plan:
- `docs/MP3_MUSIC_SETUP.md` describes attract, start, bonus, game over, and hiscore files.
- `docs/WIFI_STREAMING_SETUP.md` describes a five-song attract playlist and a WiFi streaming path with local fallback.
- `docs/SYSTEM_BEHAVIOR_CONTRACT.md` still treats music playback policy as an open decision.

## Local Audio Assets
The local `music/` folder currently contains the following Elton-related files:
- `pinball_wizard.mp3`
- `crocodile_rock.mp3`
- `bennie_jets.mp3`
- `rocket_man.mp3`
- `yellow_brick.mp3`
- `Tiny dancer clip.mp3`

This is enough to start designing the mode-to-audio mapping, but not enough to claim a final assignment for every clip.

## Planning Assumptions For This Issue
This issue should start from the following scope decisions:
- Full-song playback is attract-only for now.
- In-game continuous background music is deferred.
- WiFi streaming is deferred for the first implementation pass.
- Game start, bonus, and game over can still become future event hooks, but they are not part of the first delivery.  

## First-Pass Mapping Proposal
This is the working mapping to use for the issue thread until we validate it on the machine:

| Game mode | Proposed audio behavior | Proposed local clip |
| --- | --- | --- |
| Startup / power-up | Short startup sting, not a full song | `Tiny dancer clip.mp3` or existing tone-based startup cue |
| Attract / idle | Full-song rotation | `pinball_wizard.mp3`, `crocodile_rock.mp3`, `bennie_jets.mp3`, `rocket_man.mp3`, `yellow_brick.mp3` |
| Start / new game | One-shot fanfare | `rocket_man.mp3` |
| Ball in play | No continuous background music in phase 1 | None |
| Bonus countdown | Short game-event cue | `crocodile_rock.mp3` |
| Game over | End-of-game cue | `yellow_brick.mp3` |

The mapping above is intentionally conservative: it preserves attract-only full songs, uses the current Elton-related files already in the repo, and leaves gameplay background music for a later pass.

## Open Questions
The issue should explicitly leave these items open for the next pass:
- Which clip, if any, should represent startup versus attract?
- Should `Tiny dancer clip.mp3` be treated as a special-purpose clip, a placeholder attract track, or excluded from the first mapping?
- Should bonus and game over use short cues first, or full tracks later?
- Should the local track names be normalized before any code wiring begins?

## Recommended Next Step
Before any code change, define a simple mode-to-track table and a canonical asset naming scheme so the audio path can be wired once without revisiting the same mapping decision repeatedly.

## Acceptance Criteria For The Issue
- The issue documents the current mode names and current audio behavior without inventing new states.
- The issue distinguishes implemented behavior from documented intent.
- The issue records the current local music inventory, including the extra Tiny Dancer clip.
- The issue captures the current planning assumption that attract-only playback is the near-term target and streaming is deferred.

## Related Files
- `Captain-v2/src/control_main.cpp`
- `src/main_firmware.cpp`
- `docs/MP3_MUSIC_SETUP.md`
- `docs/WIFI_STREAMING_SETUP.md`
- `docs/SYSTEM_BEHAVIOR_CONTRACT.md`
- `HANDOFF_2026-06-05.md`

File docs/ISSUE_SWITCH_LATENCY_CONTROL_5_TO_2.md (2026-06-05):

# Switch Latency Tuning: Reduce Control Confirm Polls 5 -> 2 (Phase 1)

## Summary
Switch response feels sluggish during rapid back-to-back events (especially spinner-like behavior). The current working hypothesis is that control-side confirmation depth is adding too much delay.

## Current Behavior
- Control confirm polls are 5 in Captain-v2/src/control_main.cpp.
- Control poll cadence is 30 ms in Captain-v2/src/control_main.cpp.
- Matrix debounce is 4 ticks in Captain-v2-matrix/src/matrix_app_main.cpp.

## Proposed Change (Phase 1 Only)
- Change control confirm polls from 5 to 2.
- Do not lower control confirm below 2 in this phase.
- Keep matrix debounce unchanged for this first pass.

## Rationale
- Targets the largest control-side latency contributor first.
- Avoids matrix-side noise risk while validating responsiveness.
- Keeps false-trigger risk bounded by not going below 2 control polls.

## Out Of Scope (Phase 1)
- No matrix debounce changes yet.
- No unrelated refactors.
- No protocol redesign.

## Optional Phase 2 (Only If Needed)
- Consider matrix debounce reduction by one tick only (4 -> 3).
- Do not reduce matrix debounce to 2 due to false-trigger risk.

## Validation Plan
1. Build and upload with guarded workflow.
2. Run spinner/back-to-back switch stress checks.
3. Run switch-health monitor for 120 seconds.
4. Compare before/after: feel, missed hits, false triggers, monitor counters.

## Safety And Process Constraints
- Keep COM12 blocked.
- Use guarded flash for uploads.
- Run monitor on each validation pass.

## Suggested Commands
- powershell -ExecutionPolicy Bypass -File scripts/guarded-flash.ps1 -Target control -Action upload
- powershell -ExecutionPolicy Bypass -File scripts/Monitor-SwitchHealth.ps1 -Port COM5 -DurationSeconds 120

## Acceptance Criteria
- Noticeably improved rapid-hit responsiveness.
- No meaningful increase in false triggers.
- No regression in link/fault counters during monitor run.

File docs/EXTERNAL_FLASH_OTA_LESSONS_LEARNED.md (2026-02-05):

# External Flash OTA - Lessons Learned

## Project Overview
Successfully implemented wireless Over-The-Air (OTA) firmware updates for ESP32 pinball controller using external W25Q64 8MB SPI flash memory. This allows 850KB+ firmware updates without requiring large internal flash partitions.

---

## Critical Issues Discovered & Solutions

### 1. **W25Q64 Power Brownout During Bulk Writes**
**Problem:** Initial W25Q64 chip failed catastrophically - JEDEC ID changed from 0xEF4017 to 0x000000 (dead chip). Write verification showed bit 7 failures (0xE9 → 0x69), indicating power brownout during high-current write operations.

**Root Cause:** W25Q64 current spikes during page program operations (up to 25mA) exceeded what the AMS1117 LDO + decoupling caps could deliver stably at ~200mA total load.

**Solution:** 
- Added **100µF 16V capacitor directly to W25Q64 VCC pin**
- Replaced damaged W25Q64 chip
- Added 5ms inter-page delays in write operations for power stability
- Result: New chip works perfectly, all diagnostics PASS

**Lesson:** External SPI flash requires **dedicated bulk decoupling** (100µF+) near the chip, not just PCB-level decoupling. Power supply must handle peak currents during write cycles.

---

### 2. **Sector Erase Race Condition**
**Problem:** Firmware writes succeeded for first ~131KB, then all data became 0xFF. The corruption occurred exactly at sector boundary 0x020000 (sector 32).

**Root Cause:** Original implementation erased sectors "on-demand" during HTTP upload using `eraseNextSectorIfNeeded()`. This created a race condition:
- HTTP chunks arrived faster than sector erases could complete
- Code attempted to write to non-erased sectors
- W25Q64 can only flip 1→0 bits; writing to non-0xFF data silently fails
- Writes appeared successful (no errors) but data was corrupted

**Failed Approach:** Tried erasing ahead incrementally during `writeChunk()` calls - still raced with incoming HTTP data.

**Solution:** **Pre-erase ALL sectors before accepting any data**:
```cpp
// In startDownload() - BEFORE any HTTP data arrives:
uint32_t sectorsNeeded = (totalSize + W25Q64_SECTOR_SIZE - 1) / W25Q64_SECTOR_SIZE;
for (uint32_t i = 0; i < sectorsNeeded; i++) {
    _flash->eraseSector(W25Q64_FIRMWARE_STAGING_ADDR + (i * W25Q64_SECTOR_SIZE));
}
// NOW all sectors are guaranteed erased before writes begin
```

**Lesson:** Flash memory requires **synchronous erase-before-write** - never assume erase will complete in time when racing with asynchronous data arrival. Pre-erase everything upfront.

---

### 3. **Browser Cache Breaking OTA Updates**
**Problem:** After rebuilding firmware, uploading via web interface repeatedly showed same corrupted checksum (0xF470A4FD) despite fresh compilation. Progress display showed 650% (incorrect percentage calculation).

**Root Cause:** 
- Browser cached both file selection AND file contents
- Even though firmware.bin was rebuilt, browser served old cached data
- Progress calculation used `firmwareSize` which was updated by image parser AFTER download

**Solution:**
1. Copy fresh firmware.bin to different location with new name before upload
2. Added separate `expectedSize` field for progress calculation:
```cpp
struct OTAMetadata {
    uint32_t firmwareSize;   // Actual validated size (for flashing)
    uint32_t expectedSize;   // Expected size from Content-Length (for progress)
    // ...
};
```

**Lesson:** Web development best practice - **always force cache invalidation** when testing updated binaries. Use unique filenames or cache-busting headers.

---

### 4. **ESP32 Image Structure Parsing**
**Problem:** Initial flash validation failed with "invalid segment length 0xffffffff" even though download completed. Later, checksum validation failed with "Calculated 0x7d read 0xff" - last byte missing.

**Root Cause:** Firmware binary structure wasn't properly understood:
- ESP32 images have: header (24 bytes) → segments (header + data each) → padding → checksum byte
- Image parser tried to calculate exact size by summing segments + 1 byte
- This excluded alignment padding between last segment and checksum

**Solution:** Use actual `bytesWritten` as firmware size instead of calculating from segment table:
```cpp
// Simple and correct - flash the entire downloaded file
_metadata.firmwareSize = _metadata.bytesWritten;
```

**Lesson:** Don't over-engineer binary format parsing when you have the complete file size. The bootloader validates structure - your job is just to deliver all bytes.

---

### 5. **Multipart Upload Content-Length Mismatch**
**Problem:** HTTP Content-Length reported 2097152 bytes (2MB) but actual firmware was 853KB, causing over-allocation and confusing size displays.

**Root Cause:** Multipart form-data includes boundary markers, headers, and padding that inflate Content-Length beyond actual file size.

**Solution:** Accept size mismatch and validate against actual data received:
```cpp
// Don't trust Content-Length for multipart - use actual bytesWritten
if (_metadata.bytesWritten + len > 2 * 1024 * 1024) {  // Hard limit only
    return false;
}
```

**Lesson:** For multipart uploads, Content-Length is **approximate**. Track actual bytes received and use that for all size-dependent logic.

---

## Architecture Decisions That Worked

### 1. **Two-Stage Download-Then-Flash Design**
Instead of streaming directly to internal flash:
1. Download entire firmware to W25Q64 external flash
2. Verify integrity completely
3. Then flash from W25Q64 → internal partition

**Benefits:**
- Can retry flashing without re-downloading
- External flash survives failed flash attempts
- Better error handling and recovery
- Allows firmware validation before committing

### 2. **ESP-IDF Native OTA API**
Used `esp_ota_begin()` / `esp_ota_write()` / `esp_ota_end()` instead of Arduino Update library.

**Benefits:**
- Direct control over partition selection
- Better error reporting (ESP_ERR codes)
- Automatic bootloader integration
- Handles partition table management

### 3. **Metadata Persistence with Preferences**
Saved download state to NVS (Non-Volatile Storage) via Preferences library.

**Benefits:**
- Survives reboots during download
- Enables resume capability (future)
- Tracks OTA history
- Simple key-value API

---

## Performance Characteristics

### Timing Measurements
- **Sector Erase:** ~40ms per 4KB sector
- **Page Write:** ~3ms per 256-byte page + 5ms stability delay
- **Full Pre-Erase:** ~20 seconds for 512 sectors (2MB)
- **Download:** ~30 seconds for 853KB @ WiFi speeds
- **Flash to Internal:** ~15 seconds for 853KB
- **Total OTA Time:** ~65 seconds end-to-end

### Resource Usage
- **RAM:** 48KB used (14.8% of 327KB) - no increase from OTA code
- **Flash:** 847KB program size (86.2% of 983KB partition)
- **External Flash:** 853KB staging area @ 0x000000-0x0D0000
- **SPI Speed:** 1MHz (conservative for reliability)

---

## Hardware Requirements Validated

### Minimum Power Supply
- **3.3V Rail:** Must handle 200mA base + 25mA flash write spikes
- **Decoupling:** 100µF bulk capacitor at W25Q64 VCC (mandatory)
- **LDO:** AMS1117 3.3V confirmed sufficient with proper decoupling

### SPI Configuration
- **Clock:** 1MHz (reliable), could increase to 10MHz if tested
- **Mode:** SPI_MODE0 (CPOL=0, CPHA=0)
- **Wiring:** CS=GPIO32, CLK=33, MOSI=26, MISO=27
- **Pull-ups:** Not required (chip has internal pulls)

---

## Code Quality Improvements Made

### Debug Logging Strategy
**Original:** Verbose logging on every operation (100+ lines per OTA)
**Improved:** 
- Progress checkpoints every 128KB
- Erase progress every 256KB  
- Essential status messages only
- Result: ~15 lines total output for successful OTA

### Error Handling
- All W25Q64 operations verify WEL (Write Enable Latch) status
- First write verified byte-by-byte for hardware validation
- Image parser validates ESP32 binary structure
- Checksum verification before flashing
- Graceful fallback if OTA fails (stays on working partition)

---

## Testing Methodology That Worked

### Hardware Validation Sequence
1. JEDEC ID check (0xEF4017 = W25Q64)
2. Status register verification (WEL, BUSY bits)
3. Erase → Write → Read test at multiple addresses
4. Power-on self-test at boot

### OTA Testing Progression
1. Unit test W25Q64 driver in isolation
2. Test download without flashing
3. Test flash with known-good firmware from external flash
4. End-to-end OTA with serial monitoring
5. Power-cycle testing after successful OTA
6. Repeated OTA cycles to verify stability

---

## Future Improvements Identified

### Could Be Enhanced
1. **Resume Capability:** Save download progress and resume after power loss
2. **Compression:** GZIP firmware before storage (could save 40%+ space)
3. **Delta Updates:** Only flash changed sectors for faster updates
4. **Multiple Firmware Slots:** Store 2-3 firmware versions in 8MB flash
5. **Rollback on Failure:** Auto-revert if new firmware crashes
6. **Progress Websocket:** Real-time progress updates via websocket instead of polling

### Optimization Opportunities
- Increase SPI clock to 10MHz after stability testing
- Reduce erase scope if firmware < 1MB (currently pre-erases 2MB)
- Pipeline erase operations during download (complex but possible)
- Use DMA for SPI transfers (hardware permitting)

---

## Documentation Created
- `EXTERNAL_FLASH_OTA_LESSONS_LEARNED.md` (this file)
- `DISPLAY_BUFFER_REFERENCE.md` (pre-existing)
- `DISPLAY_IMPLEMENTATION_SUMMARY.md` (pre-existing)
- `OTA_SYSTEM_ARCHITECTURE.md` (recommended to create)

---

## Key Takeaways

1. **Hardware constraints are real** - inadequate power caused permanent chip damage
2. **Race conditions in embedded systems are subtle** - erase timing wasn't obvious until deep debugging
3. **Browser behavior matters** - cache invalidation is critical for testing
4. **Understand your binary formats** - ESP32 image structure has nuances
5. **Pre-erase is safer than on-demand erase** - synchronous operations beat async races
6. **Separate download from flash** - staging area gives flexibility and safety
7. **Good diagnostics save time** - hardware self-test caught issues early
8. **Clean code wins** - removing debug clutter made production code readable

---

## Team Knowledge Preservation

### Skills Required for Maintenance
- ESP32 partition table structure
- SPI flash memory timing characteristics  
- HTTP multipart form parsing
- ESP-IDF OTA API usage
- Binary image format validation

### Critical Files to Understand
- `src/external_flash_ota.cpp` - OTA state machine
- `src/w25q64.cpp` - SPI flash driver
- `src/ota_http_server.cpp` - Web interface
- `include/external_flash_ota.h` - Public API
- `partitions_custom.csv` - Partition layout

### Debugging Tips
- Monitor W25Q64 power rail with oscilloscope during writes
- Check JEDEC ID first if anything fails (0x000000 = dead chip)
- Look for 0xFF patterns in hex dumps to spot erase issues
- Compare firmware.bin checksums before/after upload
- Use `ESP.getFreeHeap()` to detect memory leaks

---

**Project Status:** ✅ **COMPLETE AND WORKING**  
**Date Completed:** February 5, 2026  
**Total Development Time:** ~6 hours (including debugging and chip replacement)  
**Lines of Code:** ~800 (OTA system) + ~200 (W25Q64 driver)

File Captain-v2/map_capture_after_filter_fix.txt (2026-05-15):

[MAP] rising row=0 col=0 bit=0 sw=[FF FF FF FF]
ets Jul 29 2019 12:21:46

rst:0x1 (POWERON_RESET),boot:0x13 (SPI_FAST_FLASH_BOOT)
configsip: 0, SPIWP:0xee
clk_drv:0x00,q_drv:0x00,d_drv:0x00,cs0_drv:0x00,hd_drv:0x00,wp_drv:0x00
mode:DIO, clock div:2
load:0x3fff0030,len:1184
load:0x40078000,len:13232
load:0x40080400,len:3028
entry 0x400805e4
CAPTAIN_V2 setup start
Attract config: enabled=0 period=1000 minStep=20 laps=1
Heartbeat enabled on GPIO15 (WS2812)
I2S audio ready (DIN=25 BCLK=14 LRCK=13)
Audio test: startup pattern begin
Audio test: startup pattern complete
W25Q probe JEDEC: 0xEF4018
External flash OK: W25Q128 detected (16MB)
OTA ready: host=captain-v2-control ip=192.168.0.202
Matrix device ready at 0x24 (simplified bridge mode, no HT16K33 emulation)
I2C probe display 0x70: OK (err=0)
I2C probe matrix 0x24: OK (err=0)
I2C bus: SDA=21 SCL=22 display=0x70 matrix=0x24
External flash: W25Q128 SPI CS=32 MOSI=26 MISO=27 SCK=33 size=16777216 bytes
Captain v2 control board started
Matrix link: ready=1 fault=0 wr_ok=1 wr_fail=0 rd_ok=1 rd_fail=0 diag_warn=0 sw0=0x00 sw1=0x00 sw2=0x00 sw3=0x00 sw_edges=0 sw_log=0 sup_db=0 sup_rate=0 s2_fire=0 s2_cd=0 s2_win=0 s2_ball=0
Matrix link: ready=1 fault=0 wr_ok=68 wr_fail=0 rd_ok=68 rd_fail=0 diag_warn=0 sw0=0x00 sw1=0x00 sw2=0x00 sw3=0x00 sw_edges=0 sw_log=0 sup_db=0 sup_rate=0 s2_fire=0 s2_cd=0 s2_win=0 s2_ball=0
Matrix link: ready=1 fault=0 wr_ok=135 wr_fail=0 rd_ok=135 rd_fail=0 diag_warn=0 sw0=0x00 sw1=0x00 sw2=0x00 sw3=0x00 sw_edges=0 sw_log=0 sup_db=0 sup_rate=0 s2_fire=0 s2_cd=0 s2_win=0 s2_ball=0
Matrix link: ready=1 fault=0 wr_ok=202 wr_fail=0 rd_ok=202 rd_fail=0 diag_warn=0 sw0=0x00 sw1=0x00 sw2=0x00 sw3=0x00 sw_edges=0 sw_log=0 sup_db=0 sup_rate=0 s2_fire=0 s2_cd=0 s2_win=0 s2_ball=0
Matrix link: ready=1 fault=0 wr_ok=269 wr_fail=0 rd_ok=269 rd_fail=0 diag_warn=0 sw0=0x00 sw1=0x00 sw2=0x00 sw3=0x00 sw_edges=0 sw_log=0 sup_db=0 sup_rate=0 s2_fire=0 s2_cd=0 s2_win=0 s2_ball=0
Matrix link: ready=1 fault=0 wr_ok=336 wr_fail=0 rd_ok=336 rd_fail=0 diag_warn=0 sw0=0x00 sw1=0x00 sw2=0x00 sw3=0x00 sw_edges=0 sw_log=0 sup_db=0 sup_rate=0 s2_fire=0 s2_cd=0 s2_win=0 s2_ball=0
Matrix link: ready=1 fault=0 wr_ok=403 wr_fail=0 rd_ok=403 rd_fail=0 diag_warn=0 sw0=0x00 sw1=0x00 sw2=0x00 sw3=0x00 sw_edges=0 sw_log=0 sup_db=0 sup_rate=0 s2_fire=0 s2_cd=0 s2_win=0 s2_ball=0
Matrix link: ready=1 fault=0 wr_ok=470 wr_fail=0 rd_ok=470 rd_fail=0 diag_warn=0 sw0=0x00 sw1=0x00 sw2=0x00 sw3=0x00 sw_edges=0 sw_log=0 sup_db=0 sup_rate=0 s2_fire=0 s2_cd=0 s2_win=0 s2_ball=0
Matrix link: ready=1 fault=0 wr_ok=537 wr_fail=0 rd_ok=537 rd_fail=0 diag_warn=0 sw0=0x00 sw1=0x00 sw2=0x00 sw3=0x00 sw_edges=0 sw_log=0 sup_db=0 sup_rate=0 s2_fire=0 s2_cd=0 s2_win=0 s2_ball=0
[MAP] rising row=0 col=0 bit=0 sw=[FF FF FF FF]
[MAP] rising row=6 col=0 bit=24 sw=[00 00 00 FF]
Matrix link: ready=1 fault=0 wr_ok=604 wr_fail=0 rd_ok=604 rd_fail=0 diag_warn=0 sw0=0x00 sw1=0x00 sw2=0x00 sw3=0x00 sw_edges=0 sw_log=0 sup_db=0 sup_rate=0 s2_fire=0 s2_cd=0 s2_win=0 s2_ball=0
Matrix link: ready=1 fault=0 wr_ok=671 wr_fail=0 rd_ok=671 rd_fail=0 diag_warn=0 sw0=0x00 sw1=0x00 sw2=0x00 sw3=0x00 sw_edges=0 sw_log=0 sup_db=0 sup_rate=0 s2_fire=0 s2_cd=0 s2_win=0 s2_ball=0
[MAP] rising row=6 col=0 bit=24 sw=[00 00 00 FF]
Matrix link: ready=1 fault=0 wr_ok=738 wr_fail=0 rd_ok=738 rd_fail=0 diag_warn=0 sw0=0x00 sw1=0x00 sw2=0x00 sw3=0x00 sw_edges=0 sw_log=0 sup_db=0 sup_rate=0 s2_fire=0 s2_cd=0 s2_win=0 s2_ball=0
Matrix link: ready=1 fault=0 wr_ok=805 wr_fail=0 rd_ok=805 rd_fail=0 diag_warn=0 sw0=0x00 sw1=0x00 sw2=0x00 sw3=0x00 sw_edges=0 sw_log=0 sup_db=0 sup_rate=0 s2_fire=0 s2_cd=0 s2_win=0 s2_ball=0
[MAP] rising row=4 col=0 bit=16 sw=[00 00 FF FF]
Matrix link: ready=1 fault=0 wr_ok=872 wr_fail=0 rd_ok=872 rd_fail=0 diag_warn=0 sw0=0x00 sw1=0x00 sw2=0x00 sw3=0x00 sw_edges=0 sw_log=0 sup_db=0 sup_rate=0 s2_fire=0 s2_cd=0 s2_win=0 s2_ball=0
Matrix link: ready=1 fault=0 wr_ok=939 wr_fail=0 rd_ok=939 rd_fail=0 diag_warn=0 sw0=0x00 sw1=0x00 sw2=0x00 sw3=0x00 sw_edges=0 sw_log=0 sup_db=0 sup_rate=0 s2_fire=0 s2_cd=0 s2_win=0 s2_ball=0
Matrix link: ready=1 fault=0 wr_ok=1006 wr_fail=0 rd_ok=1006 rd_fail=0 diag_warn=0 sw0=0x00 sw1=0x00 sw2=0x00 sw3=0x00 sw_edges=0 sw_log=0 sup_db=0 sup_rate=0 s2_fire=0 s2_cd=0 s2_win=0 s2_ball=0
Matrix link: ready=1 fault=0 wr_ok=1073 wr_fail=0 rd_ok=1073 rd_fail=0 diag_warn=0 sw0=0x00 sw1=0x00 sw2=0x00 sw3=0x00 sw_edges=0 sw_log=0 sup_db=0 sup_rate=0 s2_fire=0 s2_cd=0 s2_win=0 s2_ball=0
Matrix link: ready=1 fault=0 wr_ok=1140 wr_fail=0 rd_ok=1140 rd_fail=0 diag_warn=0 sw0=0x00 sw1=0x00 sw2=0x00 sw3=0x00 sw_edges=0 sw_log=0 sup_db=0 sup_rate=0 s2_fire=0 s2_cd=0 s2_win=0 s2_ball=0
Matrix link: ready=1 fault=0 wr_ok=1207 wr_fail=0 rd_ok=1207 rd_fail=0 diag_warn=0 sw0=0x00 sw1=0x00 sw2=0x00 sw3=0x00 sw_edges=0 sw_log=0 sup_db=0 sup_rate=0 s2_fire=0 s2_cd=0 s2_win=0 s2_ball=0
Matrix link: ready=1 fault=0 wr_ok=1274 wr_fail=0 rd_ok=1274 rd_fail=0 diag_warn=0 sw0=0x00 sw1=0x00 sw2=0x00 sw3=0x00 sw_edges=0 sw_log=0 sup_db=0 sup_rate=0 s2_fire=0 s2_cd=0 s2_win=0 s2_ball=0
Matrix link: ready=1 fault=0 wr_ok=1341 wr_fail=0 rd_ok=1341 rd_fail=0 diag_warn=0 sw0=0x00 sw1=0x00 sw2=0x00 sw3=0x00 sw_edges=0 sw_log=0 sup_db=0 sup_rate=0 s2_fire=0 s2_cd=0 s2_win=0 s2_ball=0
[MAP] rising row=6 col=0 bit=24 sw=[00 00 00 FF]
Matrix link: ready=1 fault=0 wr_ok=1408 wr_fail=0 rd_ok=1408 rd_fail=0 diag_warn=0 sw0=0x00 sw1=0x00 sw2=0x00 sw3=0x00 sw_edges=0 sw_log=0 sup_db=0 sup_rate=0 s2_fire=0 s2_cd=0 s2_win=0 s2_ball=0
[MAP] rising row=4 col=0 bit=16 sw=[00 00 FF FF]
Matrix link: ready=1 fault=0 wr_ok=1475 wr_fail=0 rd_ok=1475 rd_fail=0 diag_warn=0 sw0=0x00 sw1=0x00 sw2=0x00 sw3=0x00 sw_edges=0 sw_log=0 sup_db=0 sup_rate=0 s2_fire=0 s2_cd=0 s2_win=0 s2_ball=0
Matrix link: ready=1 fault=0 wr_ok=1542 wr_fail=0 rd_ok=1542 rd_fail=0 diag_warn=0 sw0=0x00 sw1=0x00 sw2=0x00 sw3=0x00 sw_edges=0 sw_log=0 sup_db=0 sup_rate=0 s2_fire=0 s2_cd=0 s2_win=0 s2_ball=0

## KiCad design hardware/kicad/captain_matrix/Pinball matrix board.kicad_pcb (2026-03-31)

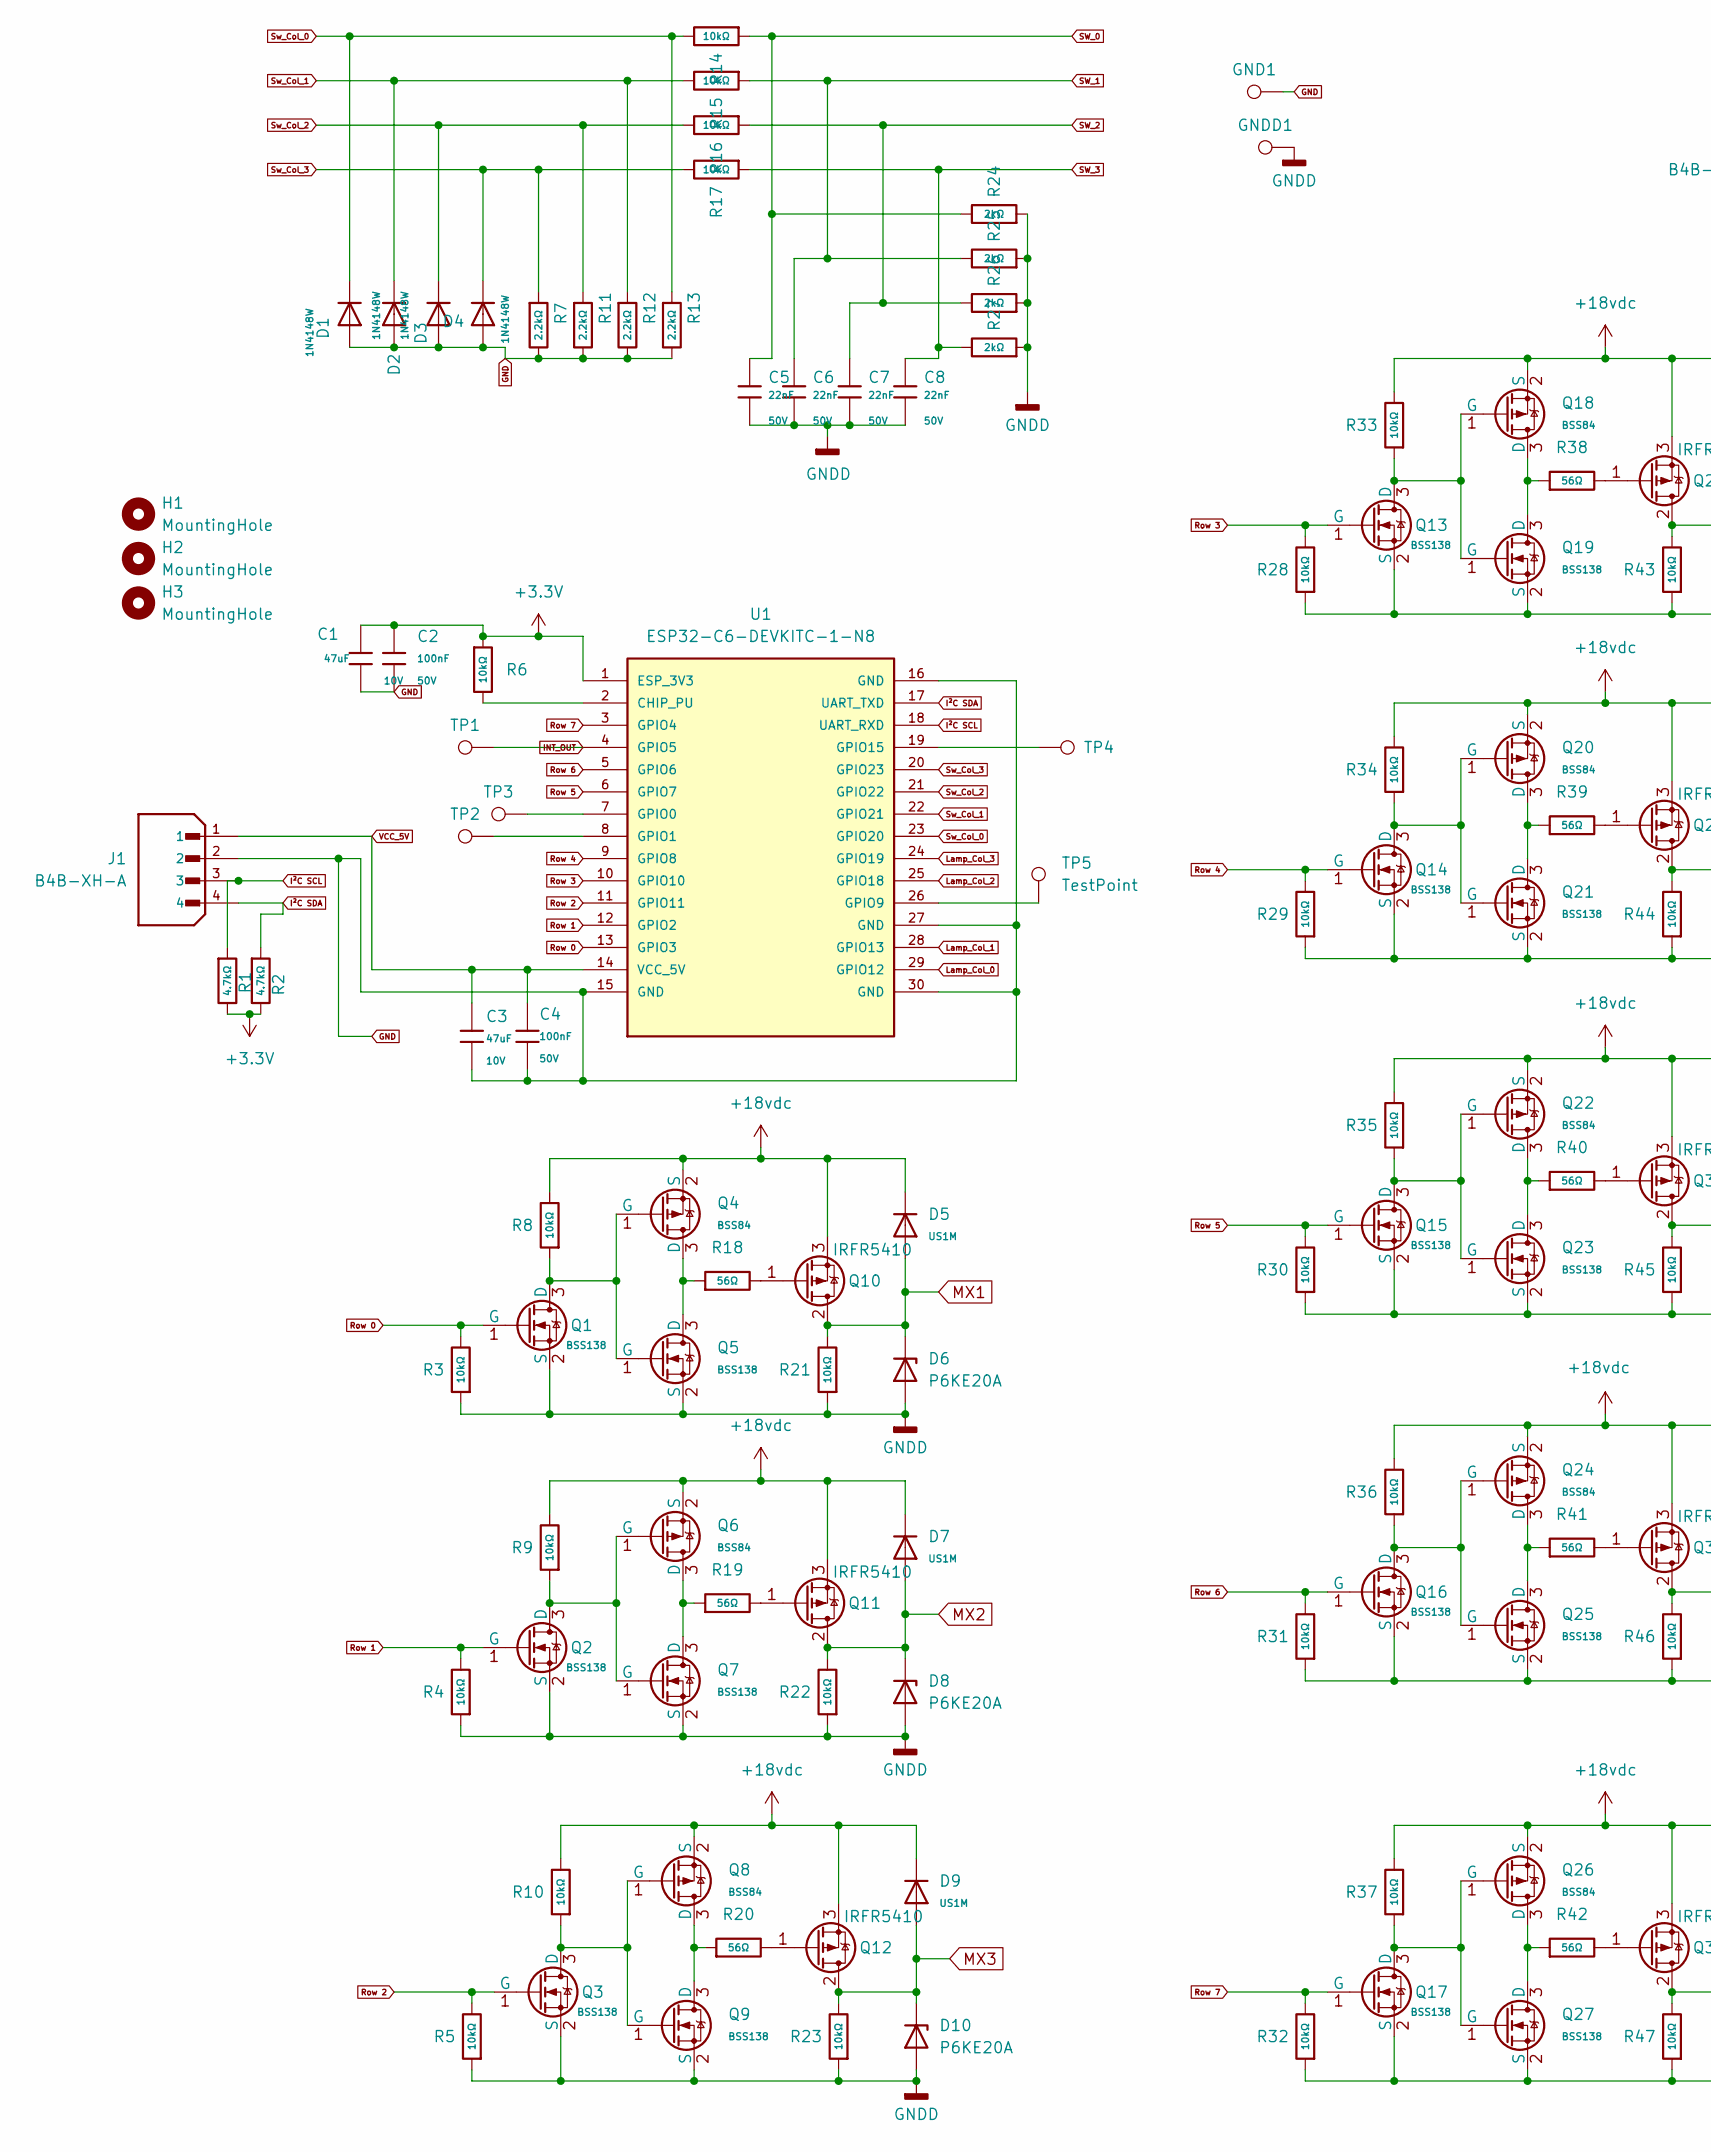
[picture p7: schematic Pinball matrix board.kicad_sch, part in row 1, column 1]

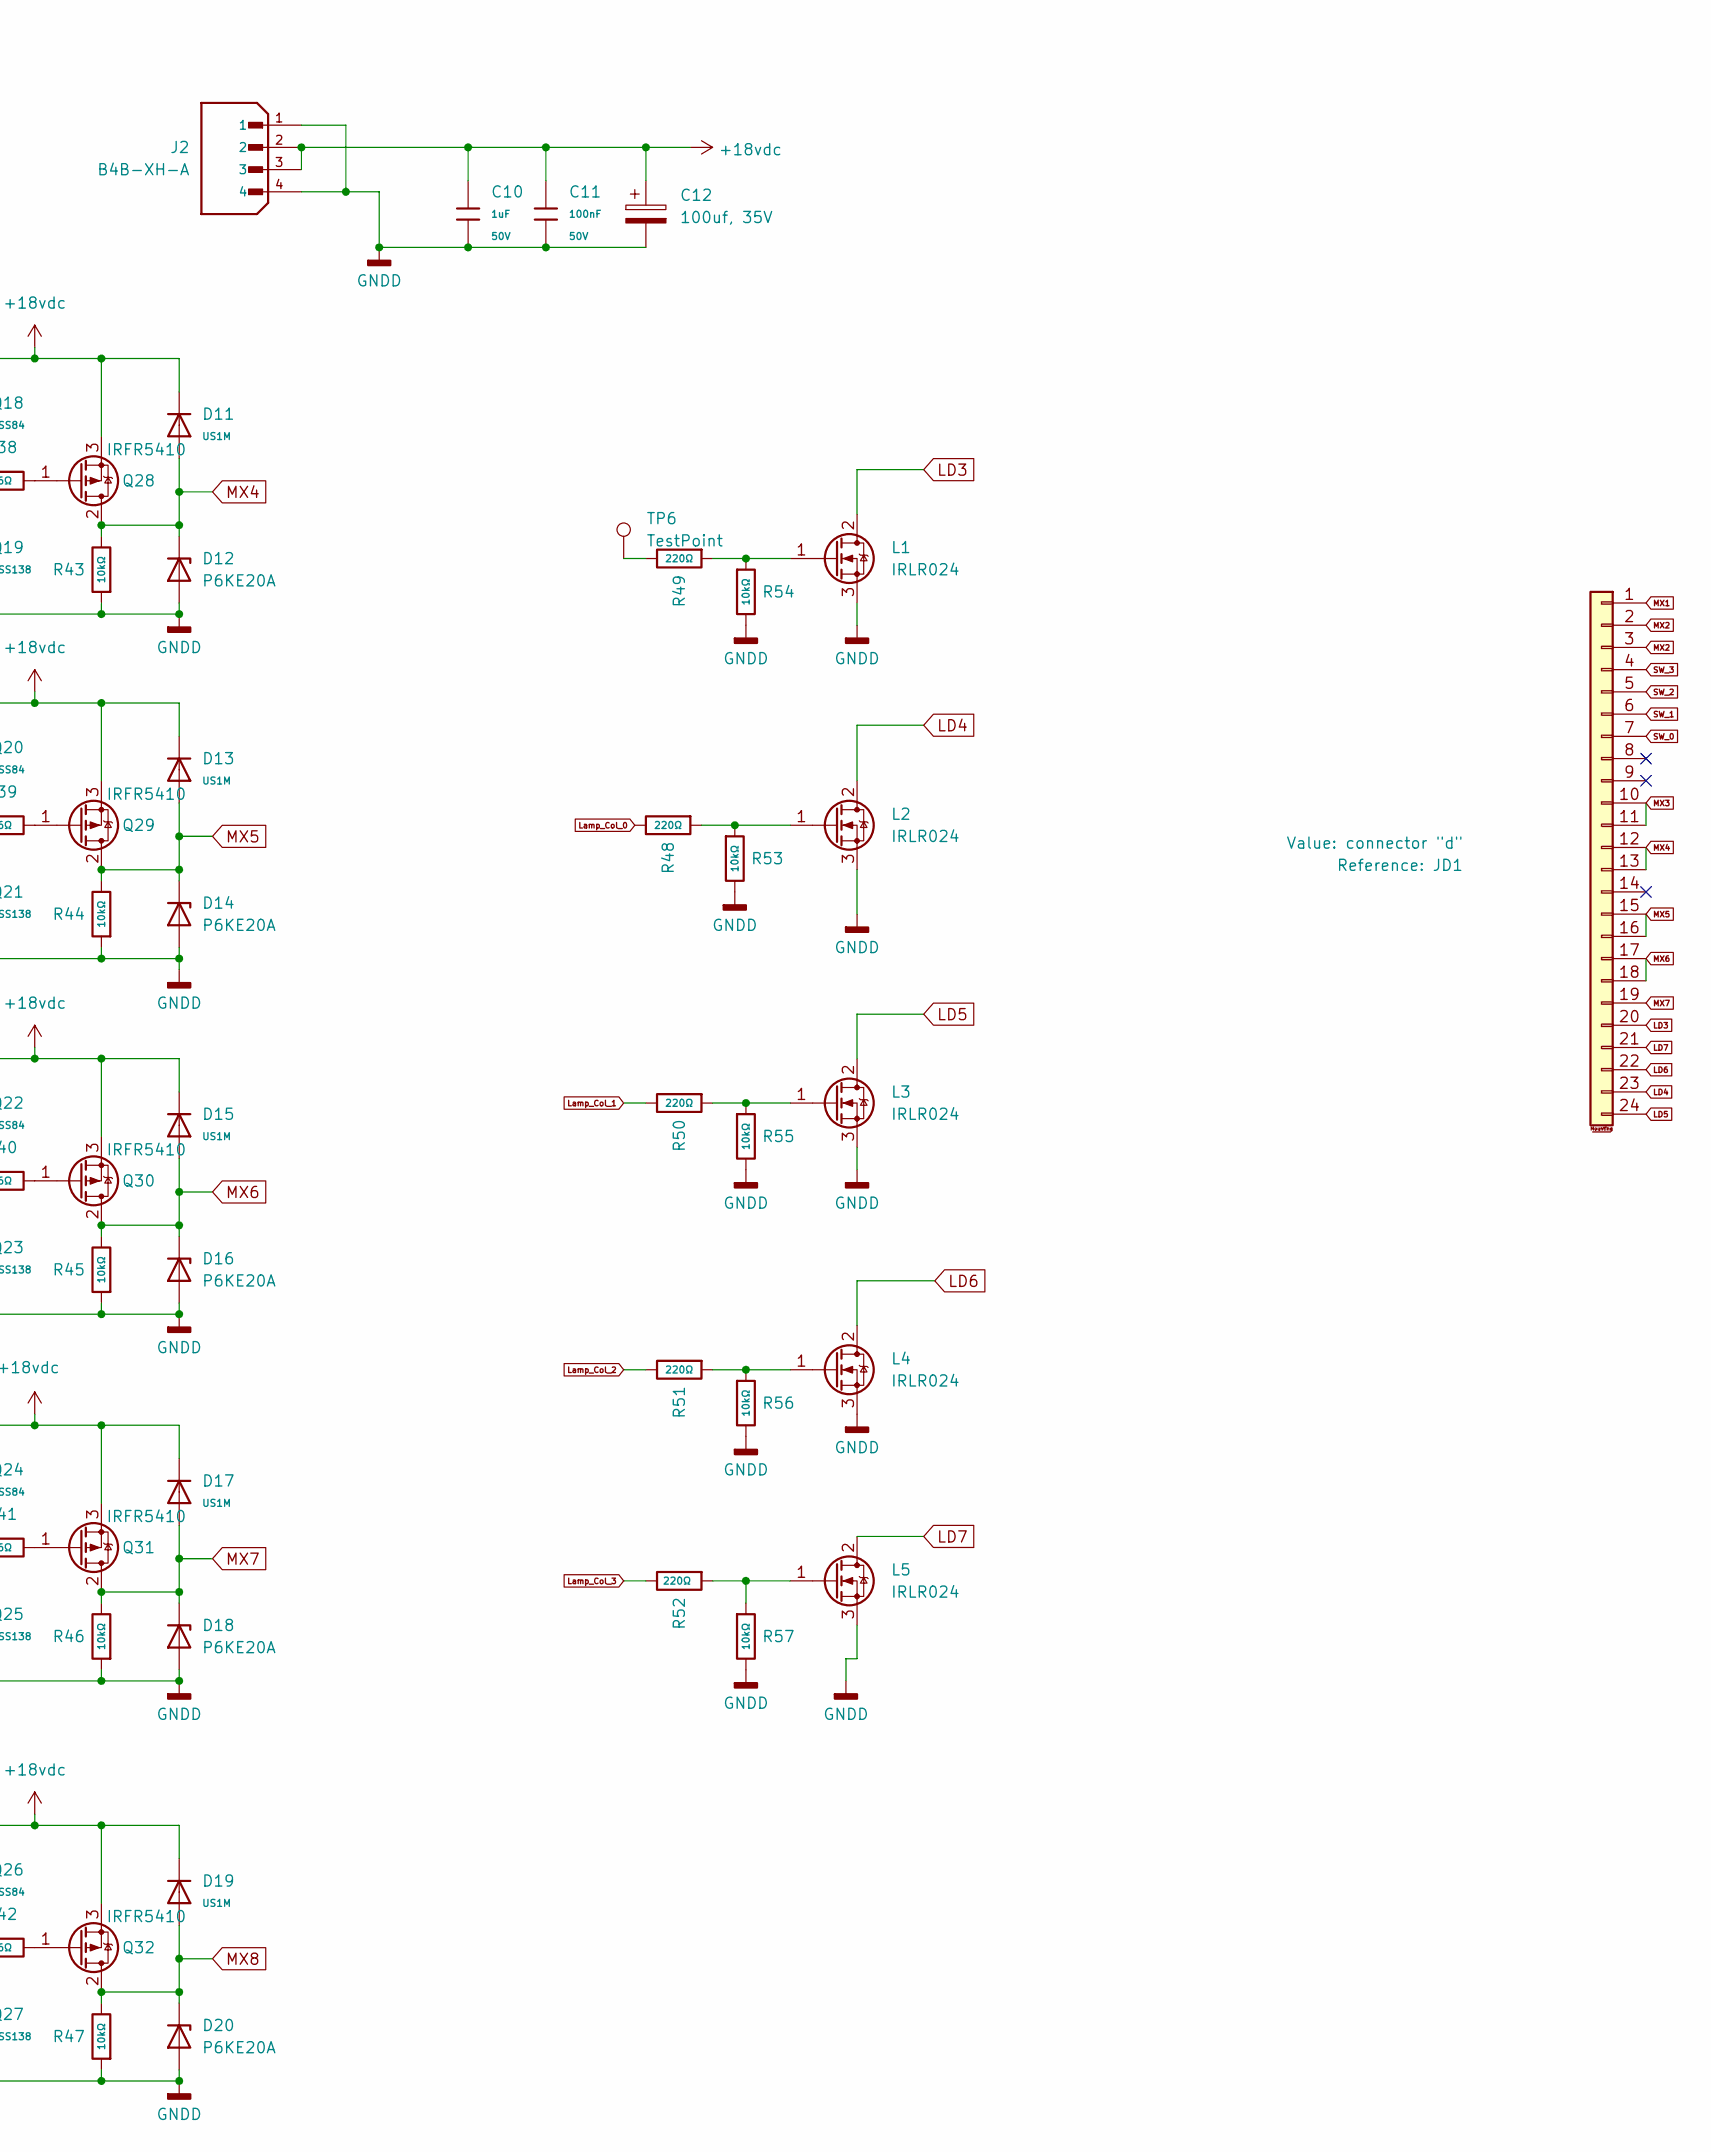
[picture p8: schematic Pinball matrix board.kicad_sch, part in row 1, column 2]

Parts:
C1, C3: 47uF; C_1206; Voltage Rated 10V; Tolerance ±20%; Part CL31A476MPHNNNE; LCSC C96123
C2, C4, C11: 100nF; C_0805; Voltage Rated 50V; Tolerance ±10%; Part CC0805KRX7R9BB104; LCSC C49678
C5, C6, C7, C8: 22nF; C_0805; Voltage Rated 50V; Tolerance ±10%; Part CL21B223KBANNNC; LCSC C1729
C10: 1uF; C_0805; Voltage Rated 50V; Tolerance ±10%; Part CL21B105KBFNNNE; LCSC C28323
C12: 100uf, 35V; CP_Radial_D6.3mm_P2.50mm; LCSC C122240
D1, D2, D3, D4: 1N4148W; D_SOD-123; Forward Voltage (Vf@If) 1V@50mA; Reverse Voltage (Vr) 75V; Part 1N4148W; LCSC C81598
D5, D7, D9, D11, D13, D15, D17, D19: US1M; D_SMA; Forward Voltage (Vf@If) 1.65V@1A; Reverse Voltage (Vr) 1kV; Part US1M; LCSC C412437
D6, D8, D10, D12, D14, D16, D18, D20: P6KE20A; D_SMC; Part SMCJ20CA; LCSC C41411754
GND1: GND; PinSocket_1x01_P2.54mm_Vertical
GNDD1: TestPoint; PinSocket_1x01_P2.54mm_Vertical
H1, H2, H3: MountingHole; MountingHole_3.5mm_Pad
J1, J2: B4B-XH-A; JST_EH_B4B-EH-A_1x04_P2.50mm_Vertical; PARTREV 7/4/21
JD1: connector "d"; Molex_KK-396_5273-12A_1x12_P3.96mm_Vertical
L1: IRLR024; TO-252-2; Manufacturer_Part_Number IRLZ44NPBF; LCSC C3007
L2, L3, L4, L5: IRLR024; TO-252-2; Mouser Part Number 942-IRLZ44NPBF
Q1, Q2, Q3, Q5, Q7, Q9, Q13, Q14, Q15, Q16, Q17, Q19, Q21, Q23, Q25, Q27: BSS138; Q_SOT-23; Part BSS138; LCSC C7420339
Q4, Q6, Q8, Q18, Q20, Q22, Q24, Q26: BSS84; Q_SOT-23; Part BSS84; LCSC C7420340
Q10, Q11, Q12, Q28, Q29, Q30, Q31, Q32: IRFR5410; TO-252-2; Manufacturer_Part_Number IRFR5410TRPBF; LCSC C3018
R1, R2: 4.7kΩ; R_0805; Overload Voltage (Max) 150V; Tolerance ±1%; Part 0805W8F4701T5E; LCSC C17673
R3, R4, R5, R6, R8, R9, R10, R14, R15, R16, R17, R21, R22, R23, R28, R29, R30, R31, R32, R33, R34, R35, R36, R37, R43, R44, R45, R46, R47, R53, R54, R55, R56, R57: 10kΩ; R_0805; Overload Voltage (Max) 150V; Tolerance ±1%; Part 0805W8F1002T5E; LCSC C17414
R7, R11, R12, R13: 2.2kΩ; R_0805; Overload Voltage (Max) 150V; Tolerance ±1%; Part 0805W8F2201T5E; LCSC C17520
R18, R19, R20, R38, R39, R40, R41, R42: 56Ω; R_0805; Overload Voltage (Max) 150V; Tolerance ±1%; Part 0805W8F560JT5E; LCSC C17757
R24, R25, R26, R27: 2kΩ; R_0805; Overload Voltage (Max) 150V; Tolerance ±1%; Part 0805W8F2001T5E; LCSC C17604
R48, R49, R50, R51, R52: 220Ω; R_0805; Overload Voltage (Max) 150V; Tolerance ±1%; Part 0805W8F2200T5E; LCSC C17557
TP1, TP2, TP3, TP4, TP5, TP6: TestPoint; PinSocket_1x01_P2.54mm_Vertical
U1: ESP32-C6-DEVKITC-1-N8; ESP32-C3-DevKitM-1; PARTREV 1.3

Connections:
+3.3V: C1.1, C2.1, R1.2, R2.2, R6.1, U1.1 (ESP_3V3)
+18vdc: C10.1, C11.1, C12.1, D5.1, D7.1, D9.1, D11.1, D13.1, D15.1, D17.1, D19.1, J2.2, J2.3, Q4.2 (S), Q6.2 (S), Q8.2 (S), Q10.3 (S), Q11.3 (S), Q12.3 (S), Q18.2 (S), Q20.2 (S), Q22.2 (S), Q24.2 (S), Q26.2 (S), Q28.3 (S), Q29.3 (S), Q30.3 (S), Q31.3 (S), Q32.3 (S), R8.2, R9.2, R10.2, R33.2, R34.2, R35.2, R36.2, R37.2
GND: C1.2, C2.2, C3.2, C4.2, D1.2, D2.2, D3.2, D4.2, GND1.1, J1.2, R7.2, R11.2, R12.2, R13.2, U1.15 (GND), U1.16 (GND), U1.27 (GND), U1.30 (GND)
GNDD: C5.2, C6.2, C7.2, C8.2, C10.2, C11.2, C12.2, D6.2 (A), D8.2 (A), D10.2 (A), D12.2 (A), D14.2 (A), D16.2 (A), D18.2 (A), D20.2 (A), GNDD1.1, J2.1, J2.4, L1.3 (S), L2.3 (S), L3.3 (S), L4.3 (S), L5.3 (S), Q1.2 (S), Q2.2 (S), Q3.2 (S), Q5.2 (S), Q7.2 (S), Q9.2 (S), Q13.2 (S), Q14.2 (S), Q15.2 (S), Q16.2 (S), Q17.2 (S), Q19.2 (S), Q21.2 (S), Q23.2 (S), Q25.2 (S), Q27.2 (S), R3.1, R4.1, R5.1, R21.1, R22.1, R23.1, R24.1, R25.1, R26.1, R27.1, R28.1, R29.1, R30.1, R31.1, R32.1, R43.1, R44.1, R45.1, R46.1, R47.1, R53.2, R54.2, R55.2, R56.2, R57.2
INT_OUT: TP1.1, U1.4 (GPIO5)
I²C SCL: J1.3, R1.1, U1.18 (UART_RXD)
I²C SDA: J1.4, R2.1, U1.17 (UART_TXD)
LD3: JD1.20, L1.2 (D)
LD4: JD1.23, L2.2 (D)
LD5: JD1.24, L3.2 (D)
LD6: JD1.22, L4.2 (D)
LD7: JD1.21, L5.2 (D)
Lamp_Col_0: R48.2, U1.29 (GPIO12)
Lamp_Col_1: R50.2, U1.28 (GPIO13)
Lamp_Col_2: R51.2, U1.25 (GPIO18)
Lamp_Col_3: R52.2, U1.24 (GPIO19)
MX1: D5.2, D6.1 (K), JD1.1, Q10.2 (D), R21.2
MX2: D7.2, D8.1 (K), JD1.2, JD1.3, Q11.2 (D), R22.2
MX3: D9.2, D10.1 (K), JD1.10, JD1.11, Q12.2 (D), R23.2
MX4: D11.2, D12.1 (K), JD1.12, JD1.13, Q28.2 (D), R43.2
MX5: D13.2, D14.1 (K), JD1.15, JD1.16, Q29.2 (D), R44.2
MX6: D15.2, D16.1 (K), JD1.17, JD1.18, Q30.2 (D), R45.2
MX7: D17.2, D18.1 (K), JD1.19, Q31.2 (D), R46.2
MX8: D19.2, D20.1 (K), Q32.2 (D), R47.2
unnamed: L1.1 (G), R49.1, R54.1
unnamed: L2.1 (G), R48.1, R53.1
unnamed: L3.1 (G), R50.1, R55.1
unnamed: L4.1 (G), R51.1, R56.1
unnamed: L5.1 (G), R52.1, R57.1
unnamed: Q1.3 (D), Q4.1 (G), Q5.1 (G), R8.1
unnamed: Q2.3 (D), Q6.1 (G), Q7.1 (G), R9.1
unnamed: Q3.3 (D), Q8.1 (G), Q9.1 (G), R10.1
unnamed: Q4.3 (D), Q5.3 (D), R18.1
unnamed: Q6.3 (D), Q7.3 (D), R19.1
unnamed: Q8.3 (D), Q9.3 (D), R20.1
unnamed: Q10.1 (G), R18.2
unnamed: Q11.1 (G), R19.2
unnamed: Q12.1 (G), R20.2
unnamed: Q13.3 (D), Q18.1 (G), Q19.1 (G), R33.1
unnamed: Q14.3 (D), Q20.1 (G), Q21.1 (G), R34.1
unnamed: Q15.3 (D), Q22.1 (G), Q23.1 (G), R35.1
unnamed: Q16.3 (D), Q24.1 (G), Q25.1 (G), R36.1
unnamed: Q17.3 (D), Q26.1 (G), Q27.1 (G), R37.1
unnamed: Q18.3 (D), Q19.3 (D), R38.1
unnamed: Q20.3 (D), Q21.3 (D), R39.1
unnamed: Q22.3 (D), Q23.3 (D), R40.1
unnamed: Q24.3 (D), Q25.3 (D), R41.1
unnamed: Q26.3 (D), Q27.3 (D), R42.1
unnamed: Q28.1 (G), R38.2
unnamed: Q29.1 (G), R39.2
unnamed: Q30.1 (G), R40.2
unnamed: Q31.1 (G), R41.2
unnamed: Q32.1 (G), R42.2
unnamed: R49.2, TP6.1
unnamed: R6.2, U1.2 (CHIP_PU)
unnamed: TP3.1, U1.7 (GPIO0)
unnamed: TP2.1, U1.8 (GPIO1)
unnamed: TP5.1, U1.26 (GPIO9)
unnamed: TP4.1, U1.19 (GPIO15)
Row 0: Q1.1 (G), R3.2, U1.13 (GPIO3)
Row 1: Q2.1 (G), R4.2, U1.12 (GPIO2)
Row 2: Q3.1 (G), R5.2, U1.11 (GPIO11)
Row 3: Q13.1 (G), R28.2, U1.10 (GPIO10)
Row 4: Q14.1 (G), R29.2, U1.9 (GPIO8)
Row 5: Q15.1 (G), R30.2, U1.6 (GPIO7)
Row 6: Q16.1 (G), R31.2, U1.5 (GPIO6)
Row 7: Q17.1 (G), R32.2, U1.3 (GPIO4)
SW_0: C5.1, JD1.7, R14.1, R24.2
SW_1: C6.1, JD1.6, R15.1, R25.2
SW_2: C7.1, JD1.5, R16.1, R26.2
SW_3: C8.1, JD1.4, R17.1, R27.2
Sw_Col_0: D1.1, R13.1, R14.2, U1.23 (GPIO20)
Sw_Col_1: D2.1, R12.1, R15.2, U1.22 (GPIO21)
Sw_Col_2: D3.1, R11.1, R16.2, U1.21 (GPIO22)
Sw_Col_3: D4.1, R7.1, R17.2, U1.20 (GPIO23)
VCC_5V: C3.1, C4.1, J1.1, U1.14 (VCC_5V)

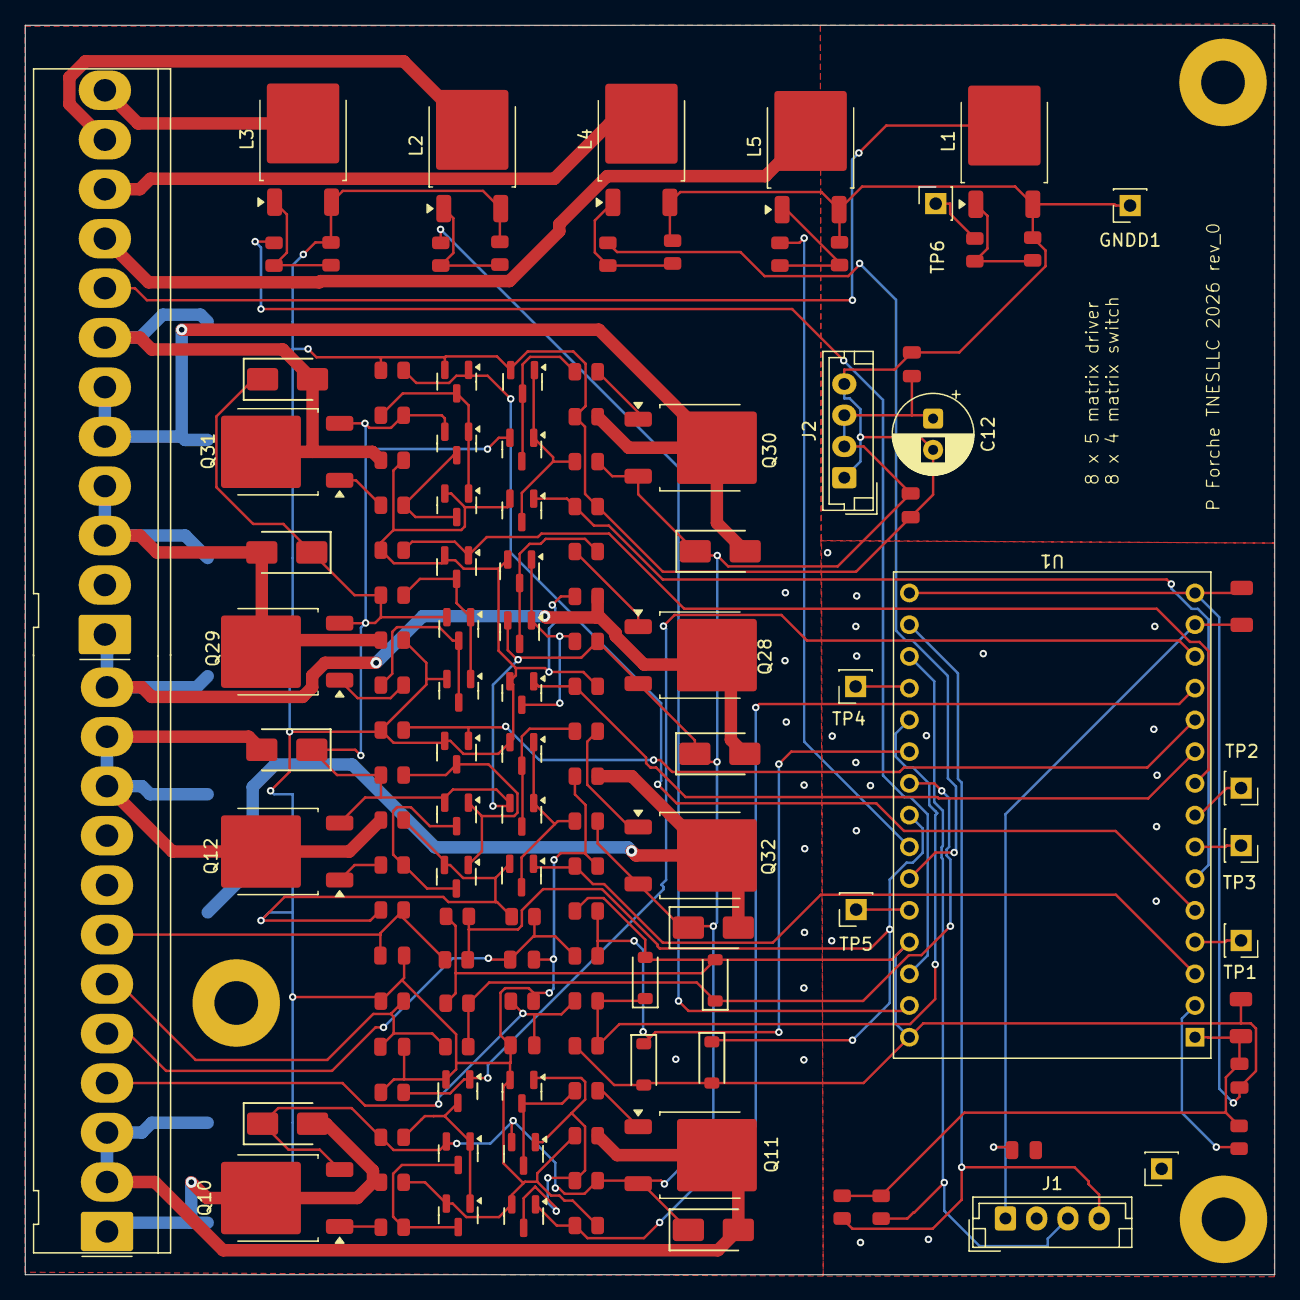
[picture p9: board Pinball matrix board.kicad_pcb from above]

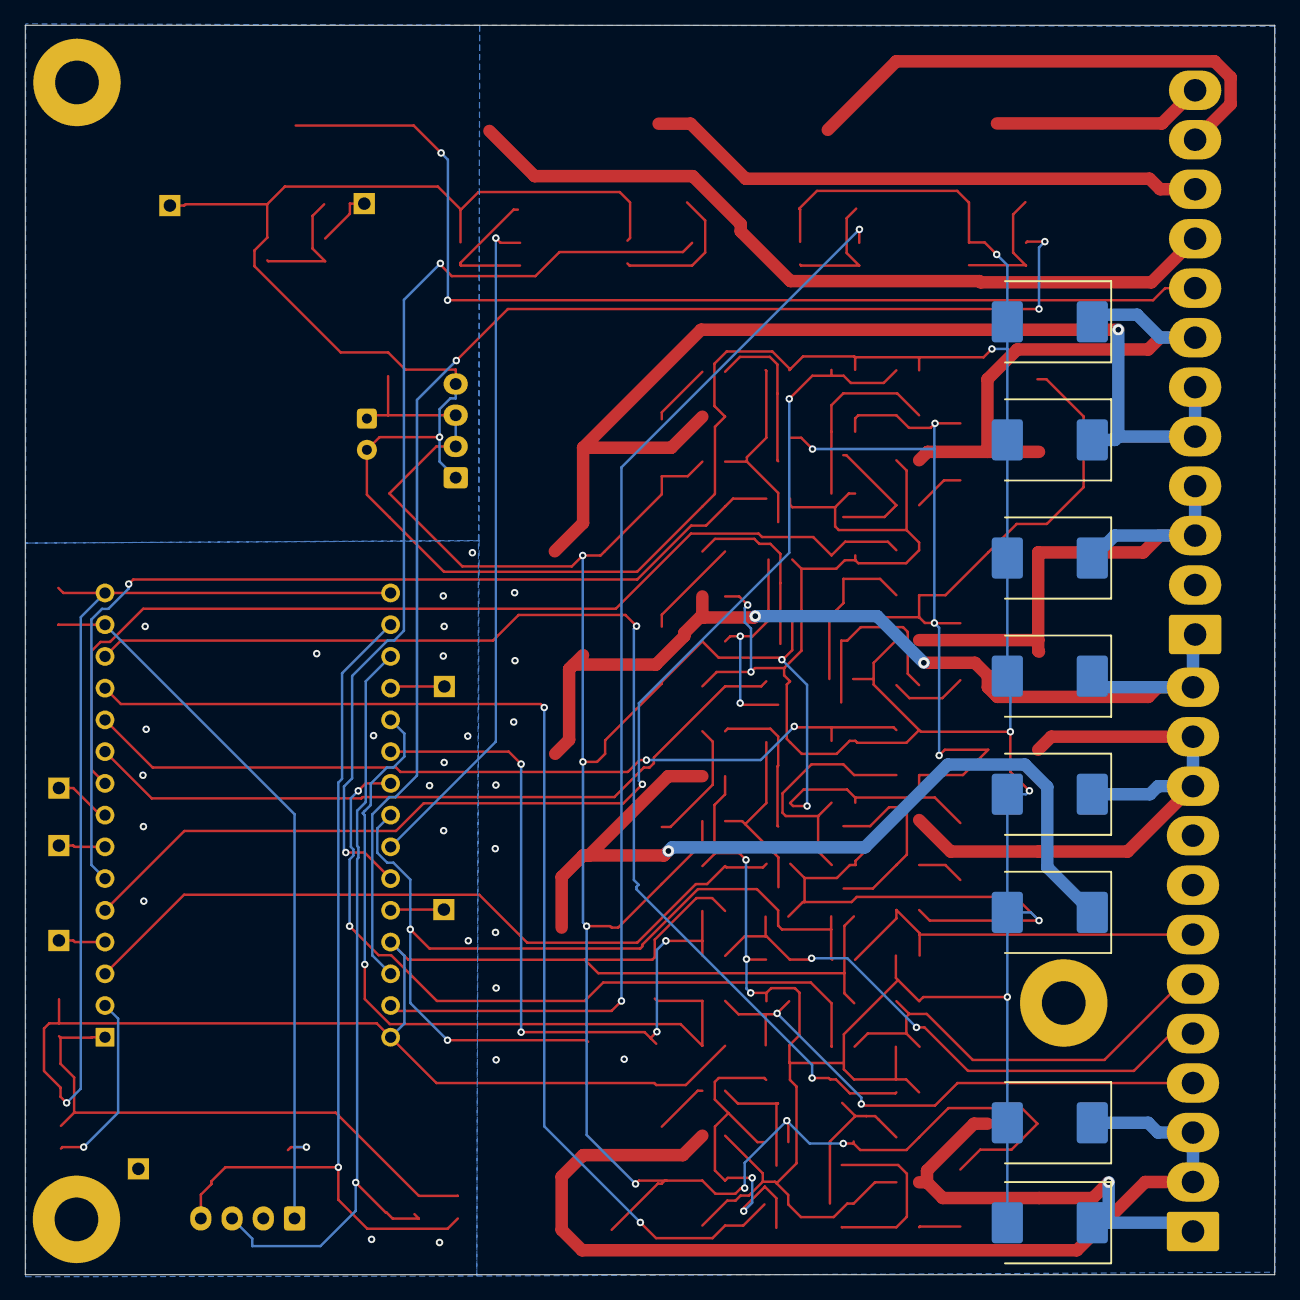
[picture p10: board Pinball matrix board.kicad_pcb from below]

Board: 2 copper layers, 100.0 x 100.0 mm, 140 parts (8 on the bottom side), 76 nets.

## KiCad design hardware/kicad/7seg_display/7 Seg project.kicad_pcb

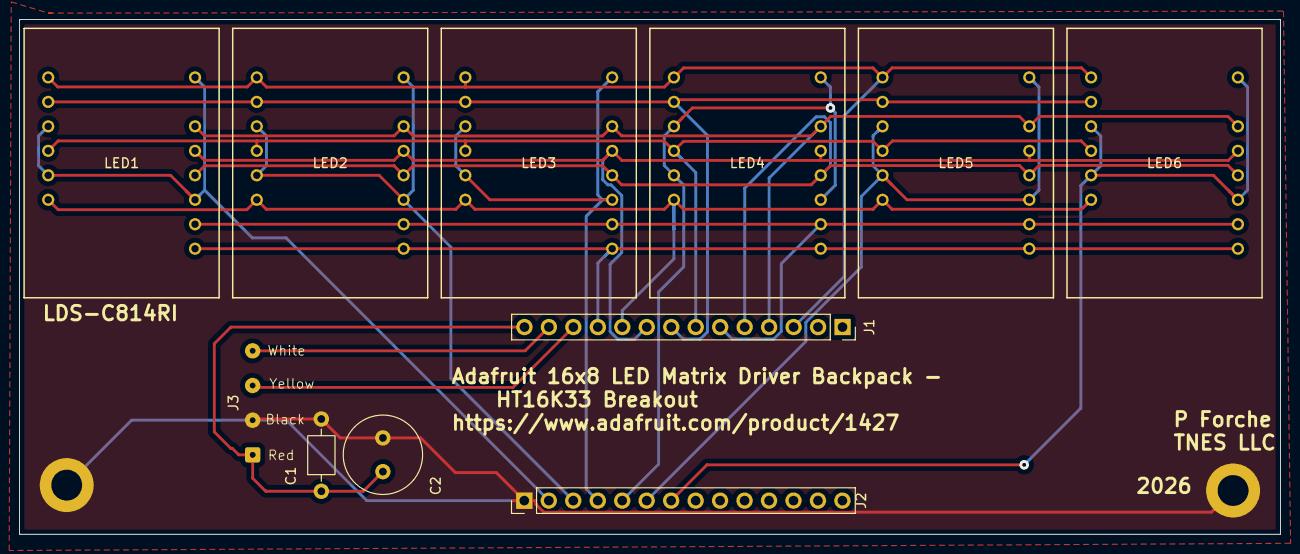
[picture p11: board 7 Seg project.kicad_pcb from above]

Board: 2 copper layers, 130.9 x 53.4 mm, 13 parts (0 on the bottom side), 19 nets.

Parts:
C1: 0.1 uf; C_Axial_L3.8mm_D2.6mm_P7.50mm_Horizontal
C2: 100uf; C_Radial_D8.0mm_H11.5mm_P3.50mm
J1, J2: Conn_01x14_Socket; PinSocket_1x14_P2.54mm_Vertical
J3: BM04B-SRSS-TB; SolderWire-0.1sqmm_1x04_P3.6mm_D0.4mm_OD1mm
LED1, LED2, LED3, LED4, LED5, LED6: LDS-C814RI; LDS-C814RI_LUM
REF 2: MountingHole_3.2mm_M3_DIN965_Pad
lb: MountingHole_3.2mm_M3_DIN965_Pad

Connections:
A0: J1.9, LED1.13 (G), LED2.13 (G), LED3.13 (G), LED4.13 (G), LED5.13 (G), LED6.13 (G)
A1: J1.10, LED1.6 (LDP), LED2.6 (LDP), LED3.6 (LDP), LED4.6 (LDP), LED5.6 (LDP), LED6.6 (LDP)
A2: J1.11, LED1.9 (RDP), LED2.9 (RDP), LED3.9 (RDP), LED4.9 (RDP), LED5.9 (RDP), LED6.9 (RDP)
ANOD3: J1.8, LED1.2 (F), LED2.2 (F), LED3.2 (F), LED4.2 (F), LED5.2 (F), LED6.2 (F)
ANOD4: J1.7, LED1.4 (E), LED2.4 (E), LED3.4 (E), LED4.4 (E), LED5.4 (E), LED6.4 (E)
ANOD5: J1.6, LED1.10 (D), LED2.10 (D), LED3.10 (D), LED4.10 (D), LED5.10 (D), LED6.10 (D)
ANOD6: J1.5, LED1.12 (C), LED2.12 (C), LED3.12 (C), LED4.12 (C), LED5.12 (C), LED6.12 (C)
ANOD7: J1.4, LED1.14 (B), LED2.14 (B), LED3.14 (B), LED4.14 (B), LED5.14 (B), LED6.14 (B)
ANOD8: J1.3, LED1.1 (A), LED2.1 (A), LED3.1 (A), LED4.1 (A), LED5.1 (A), LED6.1 (A)
CATH0: J2.2, LED1.3 (com), LED1.5 (COM), LED1.11 (COM), LED1.16 (COM)
CATH1: J2.3, LED2.3 (com), LED2.5 (COM), LED2.11 (COM), LED2.16 (COM)
CATH2: J2.4, LED3.3 (com), LED3.5 (COM), LED3.11 (COM), LED3.16 (COM)
CATH3: J2.5, LED4.3 (com), LED4.5 (COM), LED4.11 (COM), LED4.16 (COM)
CATH4: J2.6, LED5.3 (com), LED5.5 (COM), LED5.11 (COM), LED5.16 (COM)
CATH5: J2.7, LED6.3 (com), LED6.5 (COM), LED6.11 (COM), LED6.16 (COM)
GND: C1.2, C2.2, J2.1, J3.2, REF 2.1, lb.1
SDA: J1.13, J3.4
SLC: J1.12, J3.3
VDD: C1.1, C2.1, J1.14, J3.1

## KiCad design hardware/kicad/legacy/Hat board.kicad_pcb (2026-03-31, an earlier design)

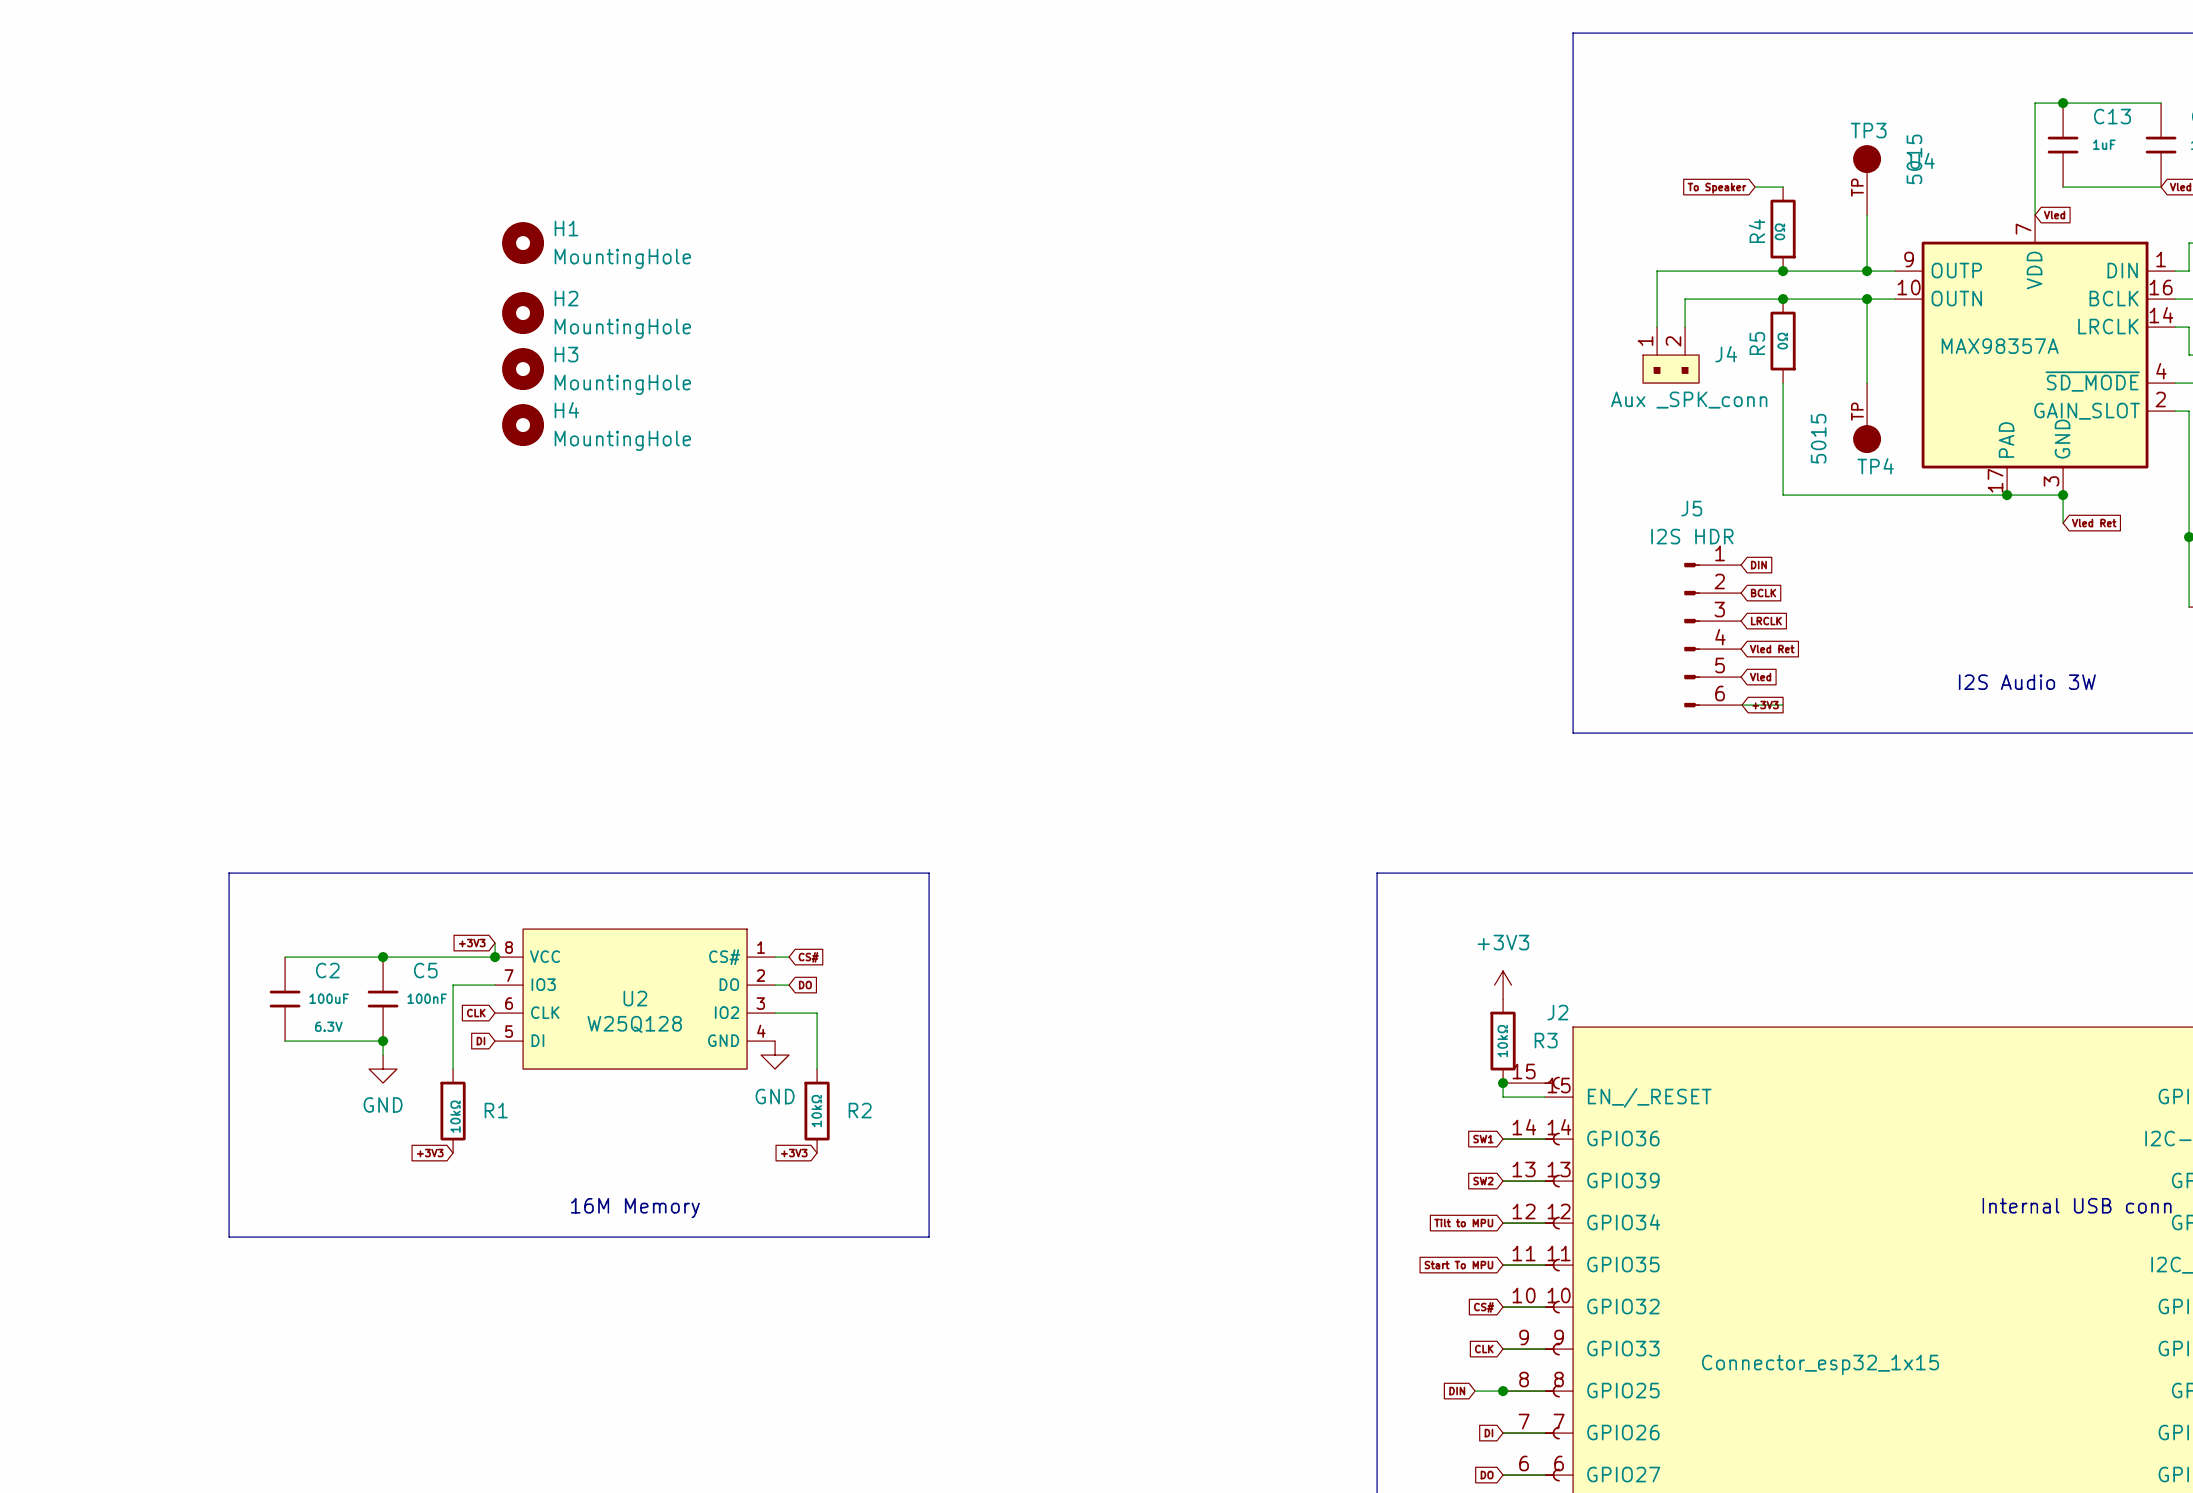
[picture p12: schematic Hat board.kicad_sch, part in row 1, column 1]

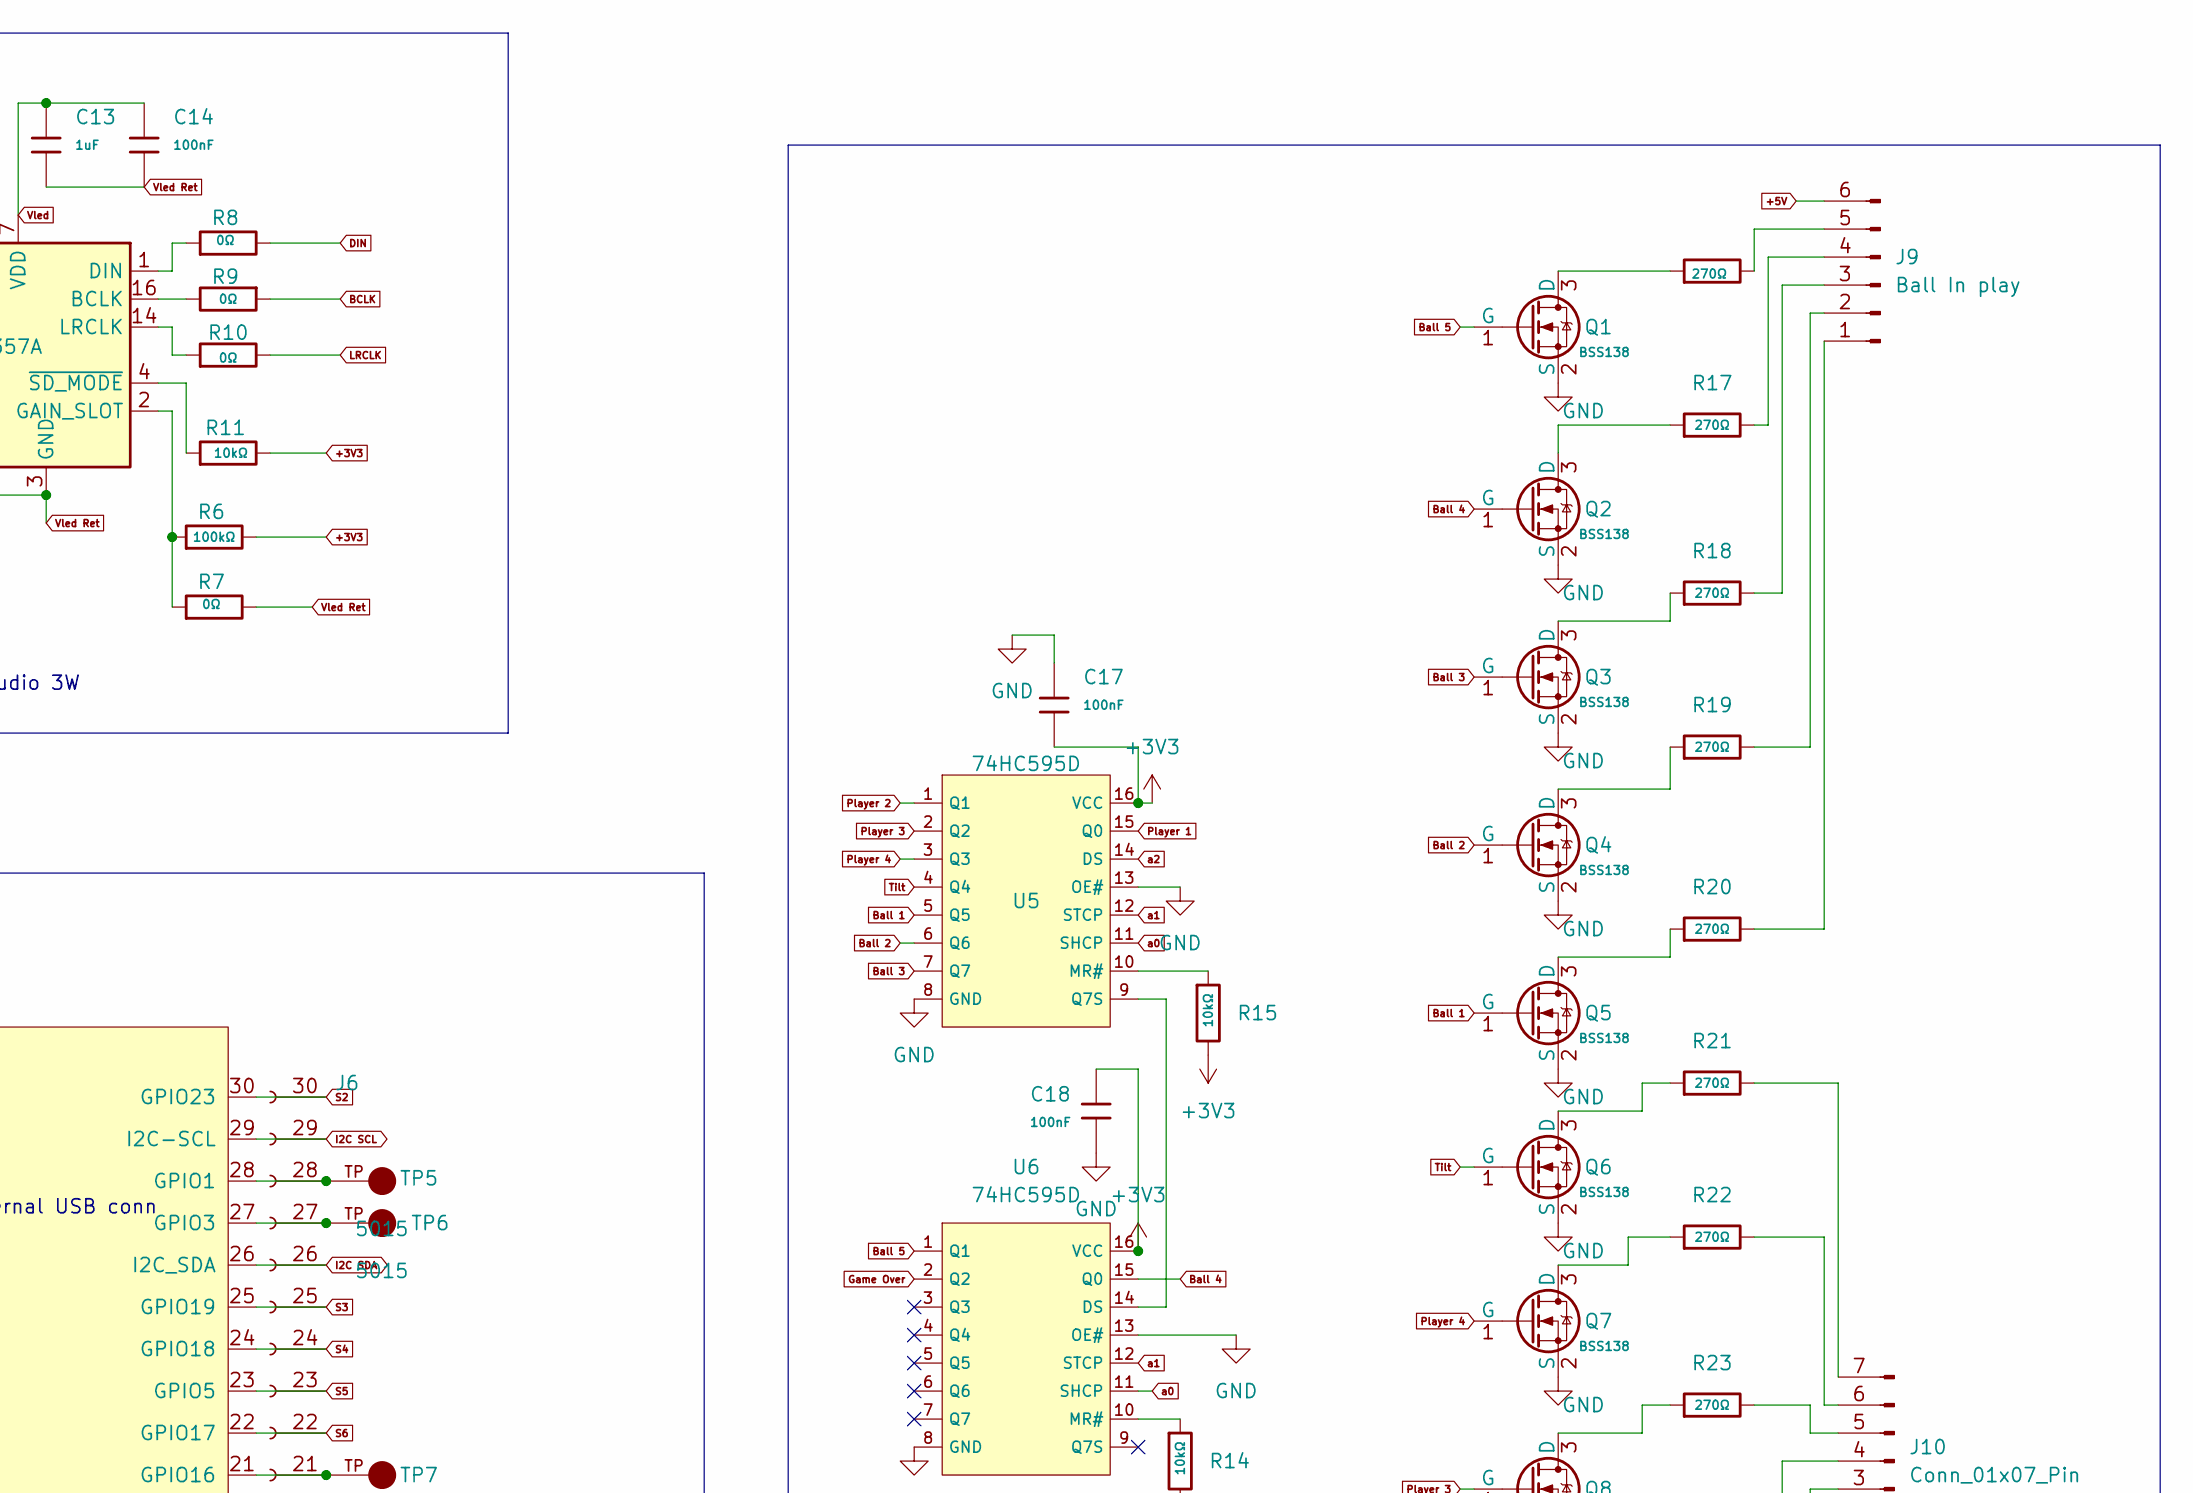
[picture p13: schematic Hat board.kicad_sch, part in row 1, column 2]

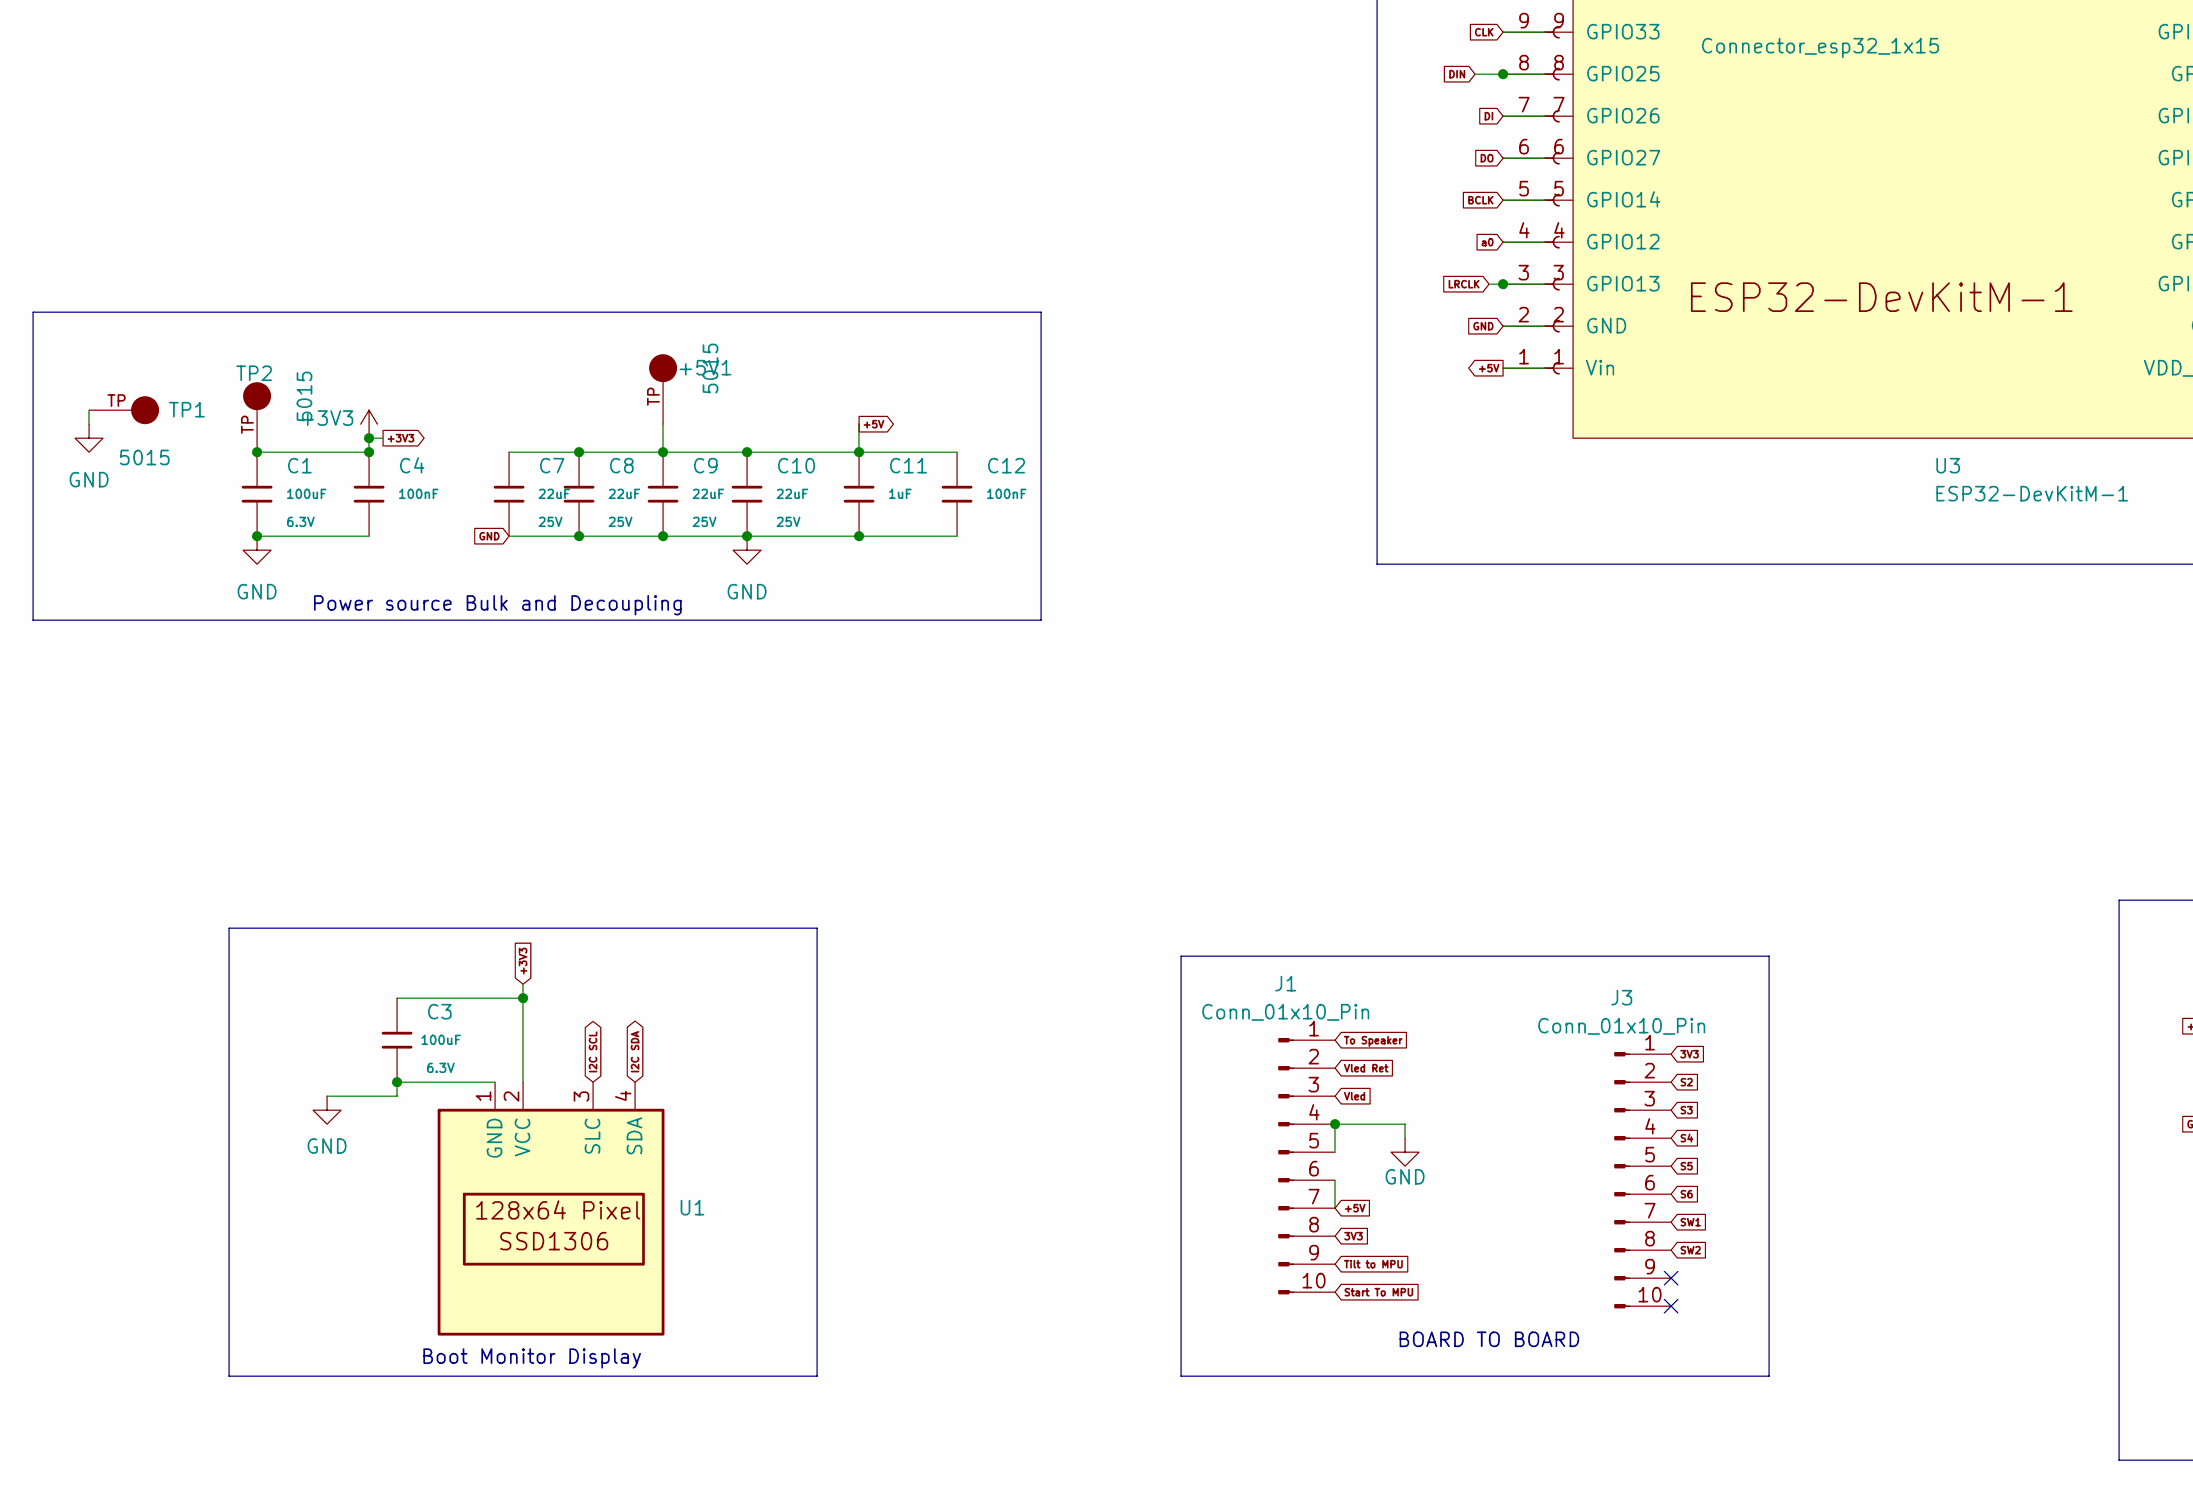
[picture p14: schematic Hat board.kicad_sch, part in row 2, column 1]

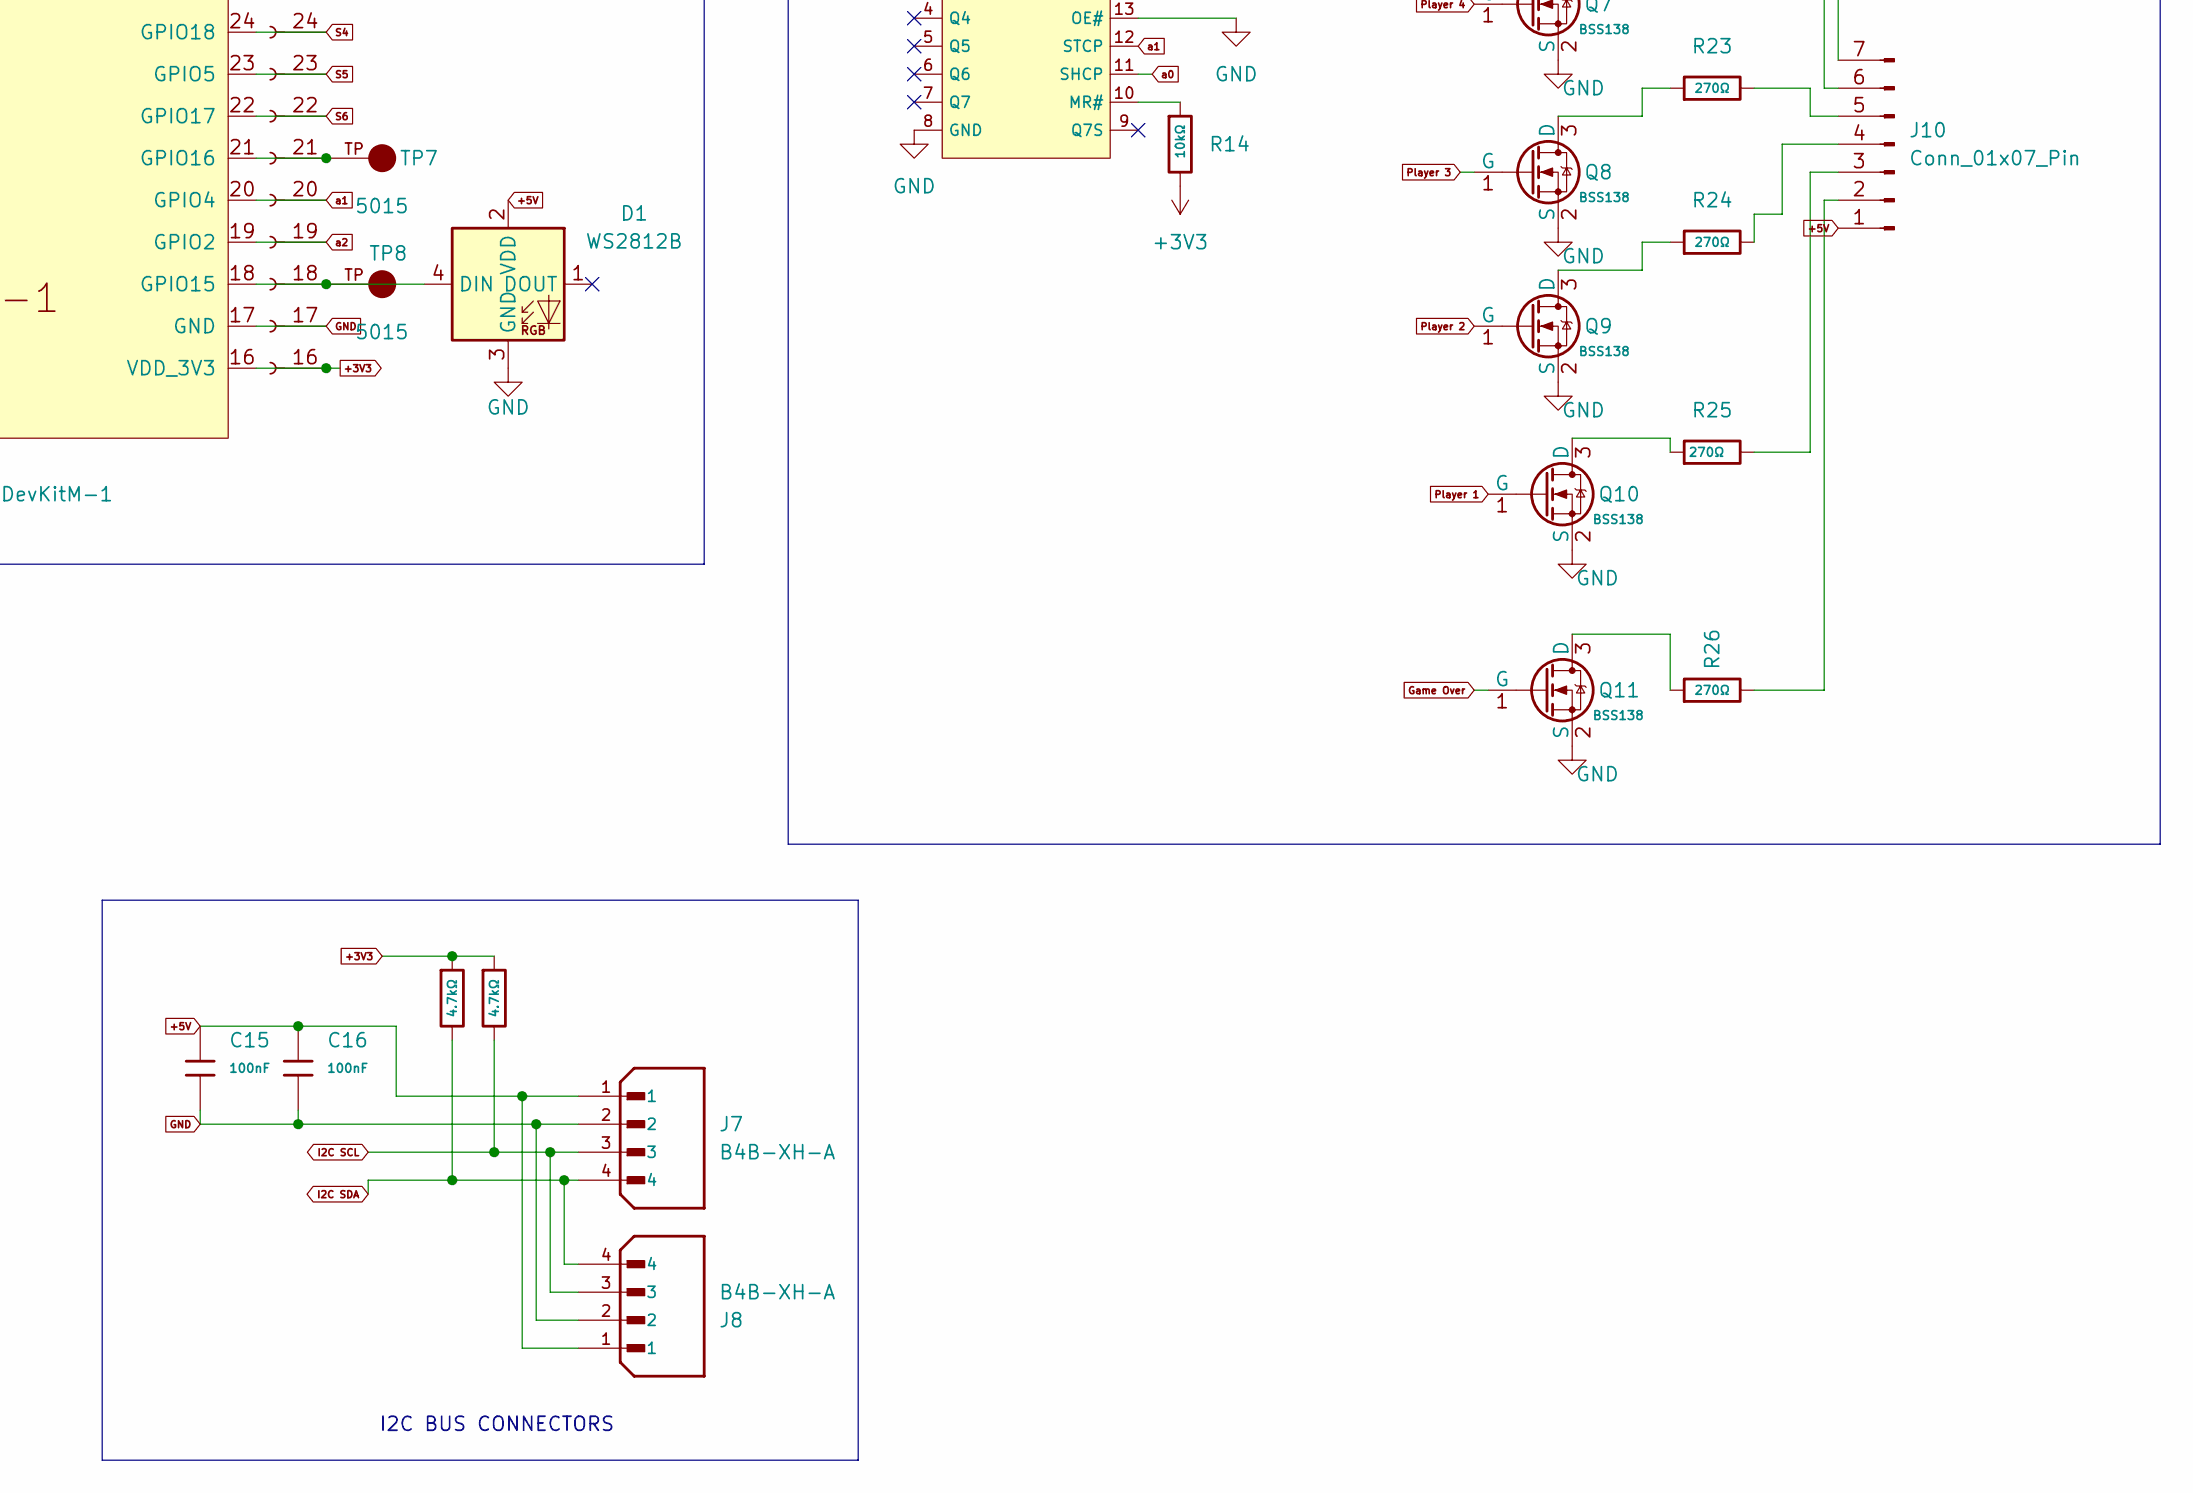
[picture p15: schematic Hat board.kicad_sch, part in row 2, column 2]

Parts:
+5V1: 5015; KEYSTONE_5015; MPN 5015; Digi-Key_PN 36-5015CT-ND
C1, C2, C3: 100uF; C_1206; Voltage Rated 6.3V; Tolerance ±20%; Part CL31A107MQHNNNE; LCSC C15008
C4, C5, C12, C14, C15, C16, C17, C18: 100nF; C_0805; Voltage Rated 50V; Tolerance ±10%; Part CC0805KRX7R9BB104; LCSC C49678
C7, C8, C9, C10: 22uF; C_0805; Voltage Rated 25V; Tolerance ±20%; Part CL21A226MAQNNNE; LCSC C45783
C11, C13: 1uF; C_0805; Voltage Rated 50V; Tolerance ±10%; Part CL21B105KBFNNNE; LCSC C28323
D1: WS2812B; LED-SMD_4P-L1.6-W1.5_XL-1615RGBC-WS2812B; LCSC C5349954
H1, H2, H3, H4: MountingHole; MountingHole_3.5mm_Pad
J1, J3: Conn_01x10_Pin; PinHeader_1x10_P2.54mm_Vertical
J2, J6: Connector_esp32_1x15; PinSocket_1x15_P2.54mm_Vertical
J4: Aux _SPK_conn; JST_XH_B2B-XH-A_1x02_P2.50mm_Vertical; MPN B2B-XH-A(LF)(SN); Digi-Key_PN 455-2247-ND
J5: I2S HDR; PinHeader_1x06_P2.54mm_Vertical_SMD_Pin1Right
J7, J8: B4B-XH-A; JST_EH_B4B-EH-A_1x04_P2.50mm_Vertical; PARTREV 7/4/21
J9: Ball In play; JST_XH_B6B-XH-AM_1x06_P2.50mm_Vertical
J10: Conn_01x07_Pin; JST_XH_B7B-XH-AM_1x07_P2.50mm_Vertical
Q1, Q2, Q3, Q4, Q5, Q6, Q7, Q8, Q9, Q10, Q11: BSS138; Q_SOT-23; Part BSS138; LCSC C7420339
R1, R2, R3, R11, R14, R15: 10kΩ; R_0805; Overload Voltage (Max) 150V; Tolerance ±1%; Part 0805W8F1002T5E; LCSC C17414
R4, R5, R7, R8, R9, R10: 0Ω; R_0805; Overload Voltage (Max) 150V; Tolerance ±1%; Part 0805W8F0000T5E; LCSC C17477
R6: 100kΩ; R_0805; Overload Voltage (Max) 150V; Tolerance ±1%; Part 0805W8F1003T5E; LCSC C149504
R12, R13: 4.7kΩ; R_0805; Overload Voltage (Max) 150V; Tolerance ±1%; Part 0805W8F4701T5E; LCSC C17673
R16, R17, R18, R19, R20, R21, R22, R23, R24, R25, R26: 270Ω; R_0805; Overload Voltage (Max) 150V; Tolerance ±1%; Part 0805W8F2700T5E; LCSC C17590
TP1, TP2, TP3, TP4, TP6, TP7, TP8: 5015; KEYSTONE_5015; MPN 5015; Digi-Key_PN 36-5015CT-ND
TP5: 5015; KEYSTONE_5015; Part 5015; LCSC C5199798
U1: ).96 inOLED display SSD1306
U2: W25Q128; SOIC-8_L5.3-W5.3-P1.27-LS8.0-BL; Part W25Q128JVSIQ; LCSC C97521
U3: ESP32-DevKitM-1
U4: MAX98357A; TQFN-16-1EP_3x3mm_P0.5mm_EP1.23x1.23mm
U5, U6: 74HC595D; SOIC-16_L9.9-W3.9-P1.27-LS6.0-BL; Supply Voltage 2V~6V; Part 74HC595D,118; LCSC C5947

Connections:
3V3: J1.8, J3.1
+3V3: C1.1, C2.1, C3.1, C4.1, C5.1, C17.2, C18.1, J5.6, J6.16 (VDD_3V3), R1.2, R2.2, R3.1, R6.2, R11.2, R12.1, R13.1, R14.2, R15.2, TP2.TP, U1.2 (VCC), U2.8 (VCC), U3.16 (VDD_3V3), U5.16 (VCC), U6.16 (VCC)
+5V: +5V1.TP, C7.1, C8.1, C9.1, C10.1, C11.1, C12.1, C15.1, C16.1, D1.2 (VDD), J1.6, J1.7, J2.1 (Vin), J7.1, J8.1, J9.6, J10.1, U3.1 (Vin)
BCLK: J2.5 (GPIO14), J5.2, R9.1, U3.5 (GPIO14)
Ball 1: Q5.1 (G), U5.5 (Q5)
Ball 2: Q4.1 (G), U5.6 (Q6)
Ball 3: Q3.1 (G), U5.7 (Q7)
Ball 4: Q2.1 (G), U6.15 (Q0)
Ball 5: Q1.1 (G), U6.1 (Q1)
CLK: J2.9 (GPIO33), U2.6 (CLK), U3.9 (GPIO33)
CS#: J2.10 (GPIO32), U2.1 (CS#), U3.10 (GPIO32)
DI: J2.7 (GPIO26), U2.5 (DI), U3.7 (GPIO26)
DIN: J2.8 (GPIO25), J5.1, R8.2, U3.8 (GPIO25)
DO: J2.6 (GPIO27), U2.2 (DO), U3.6 (GPIO27)
GND: C1.2, C2.2, C3.2, C4.2, C5.2, C7.2, C8.2, C9.2, C10.2, C11.2, C12.2, C15.2, C16.2, C17.1, C18.2, D1.3 (GND), H2.1, J1.4, J1.5, J2.2 (GND), J6.17 (GND), J7.2, J8.2, Q1.2 (S), Q2.2 (S), Q3.2 (S), Q4.2 (S), Q5.2 (S), Q6.2 (S), Q7.2 (S), Q8.2 (S), Q9.2 (S), Q10.2 (S), Q11.2 (S), TP1.TP, U1.1 (GND), U2.4 (GND), U3.2 (GND), U3.17 (GND), U5.8 (GND), U5.13 (OE#), U6.8 (GND), U6.13 (OE#)
Game Over: Q11.1 (G), U6.2 (Q2)
I2C SCL: J6.29 (I2C-SCL), J7.3, J8.3, R13.2, U1.3 (SLC), U3.29 (I2C-SCL)
I2C SDA: J6.26 (I2C_SDA), J7.4, J8.4, R12.2, U1.4 (SDA), U3.26 (I2C_SDA)
LRCLK: J2.3 (GPIO13), J5.3, R10.2, U3.3 (GPIO13)
unnamed: D1.4 (DIN), J6.18 (GPIO15), TP8.TP, U3.18 (GPIO15)
unnamed: J2.15 (EN_/_RESET), R3.2, U3.15 (EN_/_RESET)
unnamed: J6.28 (GPIO1), TP5.TP, U3.28 (GPIO1)
unnamed: J6.27 (GPIO3), TP6.TP, U3.27 (GPIO3)
unnamed: J6.21 (GPIO16), TP7.TP, U3.21 (GPIO16)
unnamed: J9.1, R20.2
unnamed: J9.2, R19.2
unnamed: J9.3, R18.2
unnamed: J9.4, R17.2
unnamed: J9.5, R16.2
unnamed: J10.2, R26.2
unnamed: J10.3, R25.2
unnamed: J10.4, R24.2
unnamed: J10.5, R23.2
unnamed: J10.6, R22.2
unnamed: J10.7, R21.2
unnamed: Q1.3 (D), R16.1
unnamed: Q2.3 (D), R17.1
unnamed: Q3.3 (D), R18.1
unnamed: Q4.3 (D), R19.1
unnamed: Q5.3 (D), R20.1
unnamed: Q6.3 (D), R21.1
unnamed: Q7.3 (D), R22.1
unnamed: Q8.3 (D), R23.1
unnamed: Q9.3 (D), R24.1
unnamed: Q10.3 (D), R25.1
unnamed: Q11.3 (D), R26.1
unnamed: R2.1, U2.3 (IO2)
unnamed: R1.1, U2.7 (IO3)
unnamed: R9.2, U4.16 (BCLK)
unnamed: R8.1, U4.1 (DIN)
unnamed: R6.1, R7.1, U4.2 (GAIN_SLOT)
unnamed: R10.1, U4.14 (LRCLK)
unnamed: J4.2, R5.2, TP4.TP, U4.10 (OUTN)
unnamed: J4.1, R4.1, TP3.TP, U4.9 (OUTP)
unnamed: R11.1, U4.4 (~SD_MODE)
unnamed: R15.1, U5.10 (MR#)
unnamed: U5.9 (Q7S), U6.14 (DS)
unnamed: R14.1, U6.10 (MR#)
Player 1: Q10.1 (G), U5.15 (Q0)
Player 2: Q9.1 (G), U5.1 (Q1)
Player 3: Q8.1 (G), U5.2 (Q2)
Player 4: Q7.1 (G), U5.3 (Q3)
S2: J3.2, J6.30 (GPIO23), U3.30 (GPIO23)
S3: J3.3, J6.25 (GPIO19), U3.25 (GPIO19)
S4: J3.4, J6.24 (GPIO18), U3.24 (GPIO18)
S5: J3.5, J6.23 (GPIO5), U3.23 (GPIO5)
S6: J3.6, J6.22 (GPIO17), U3.22 (GPIO17)
SW1: J2.14 (GPIO36), J3.7, U3.14 (GPIO36)
SW2: J2.13 (GPIO39), J3.8, U3.13 (GPIO39)
Start To MPU: J1.10, J2.11 (GPIO35), U3.11 (GPIO35)
Tilt: Q6.1 (G), U5.4 (Q4)
Tilt to MPU: J1.9, J2.12 (GPIO34), U3.12 (GPIO34)
To Speaker: J1.1, R4.2
Vled: C13.1, C14.1, J1.3, J5.5, U4.7 (VDD), U4.8 (VDD)
Vled Ret: C13.2, C14.2, J1.2, J5.4, R5.1, R7.2, U4.3 (GND), U4.11 (GND), U4.15 (GND), U4.17 (PAD)
a0: J2.4 (GPIO12), U3.4 (GPIO12), U5.11 (SHCP), U6.11 (SHCP)
a1: J6.20 (GPIO4), U3.20 (GPIO4), U5.12 (STCP), U6.12 (STCP)
a2: J6.19 (GPIO2), U3.19 (GPIO2), U5.14 (DS)

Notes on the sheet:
BOARD TO BOARD
Power source Bulk and Decoupling
I2C BUS CONNECTORS
Boot Monitor Display
16M Memory
Internal USB conn
I2S Audio 3W

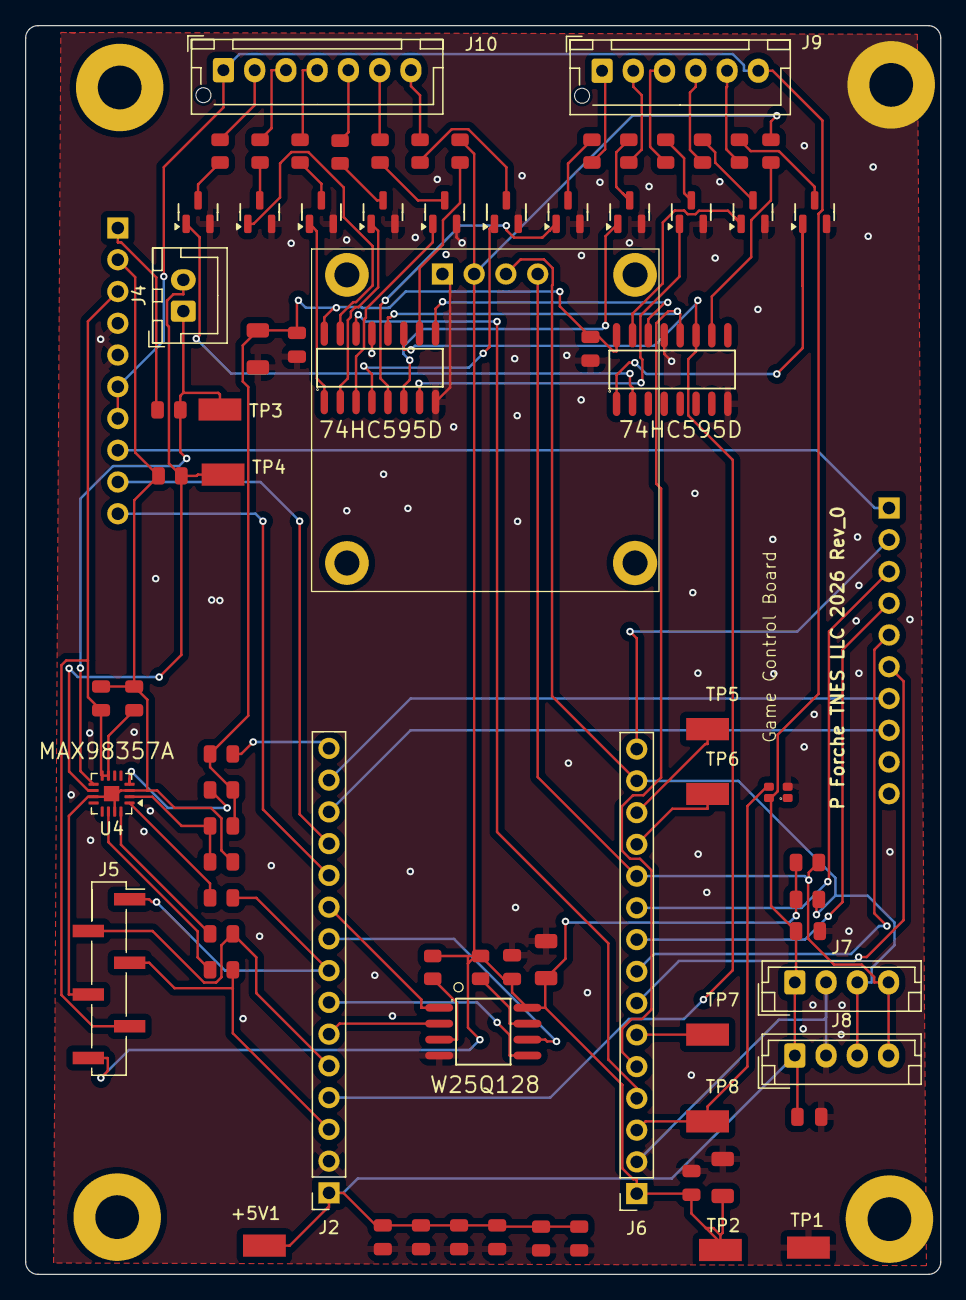
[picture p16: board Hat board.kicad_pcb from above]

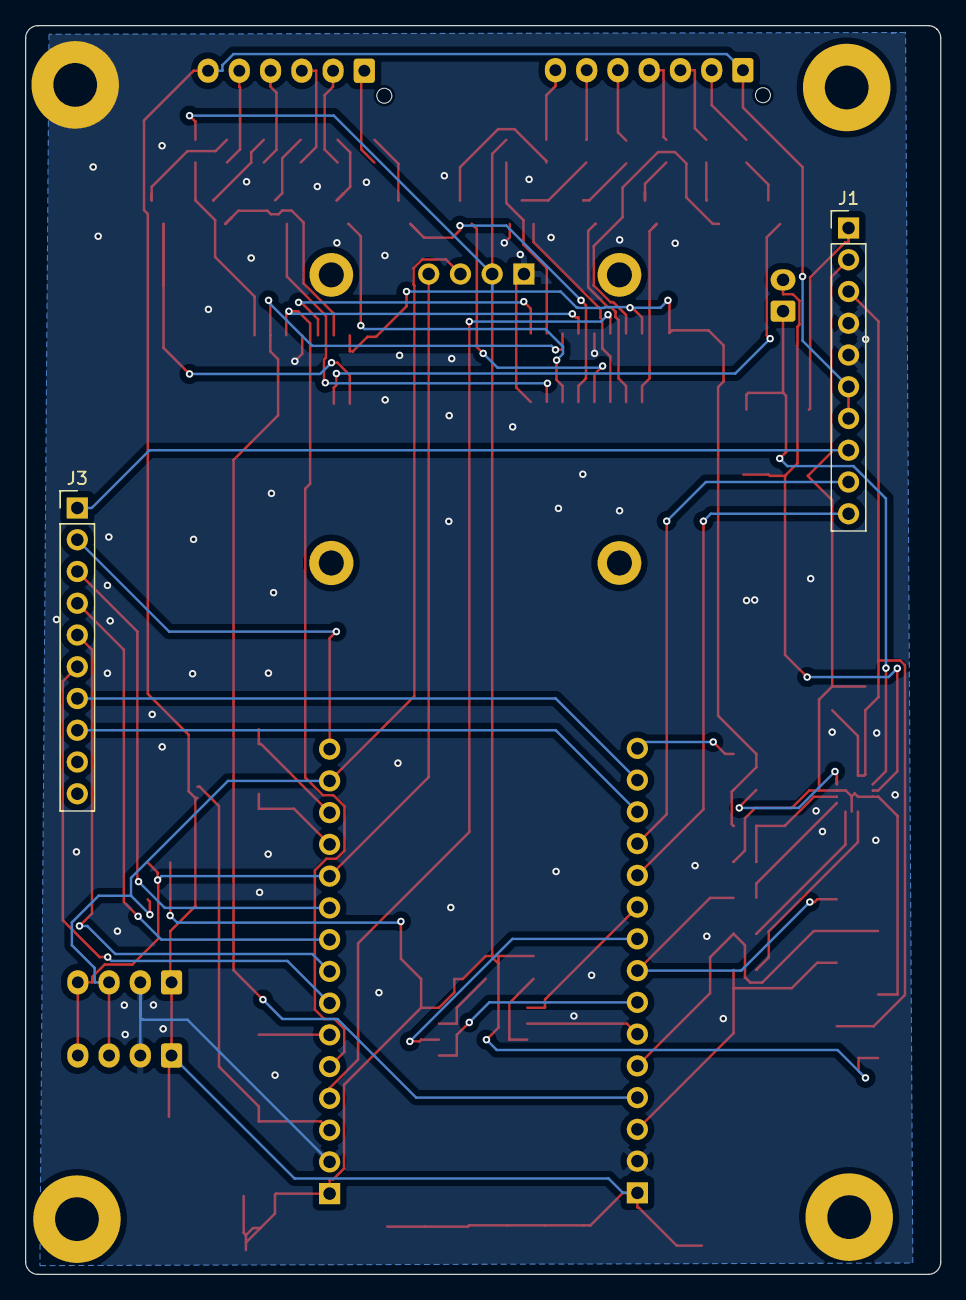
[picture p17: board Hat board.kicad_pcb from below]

Board: 2 copper layers, 73.2 x 99.9 mm, 83 parts (2 on the bottom side), 78 nets.

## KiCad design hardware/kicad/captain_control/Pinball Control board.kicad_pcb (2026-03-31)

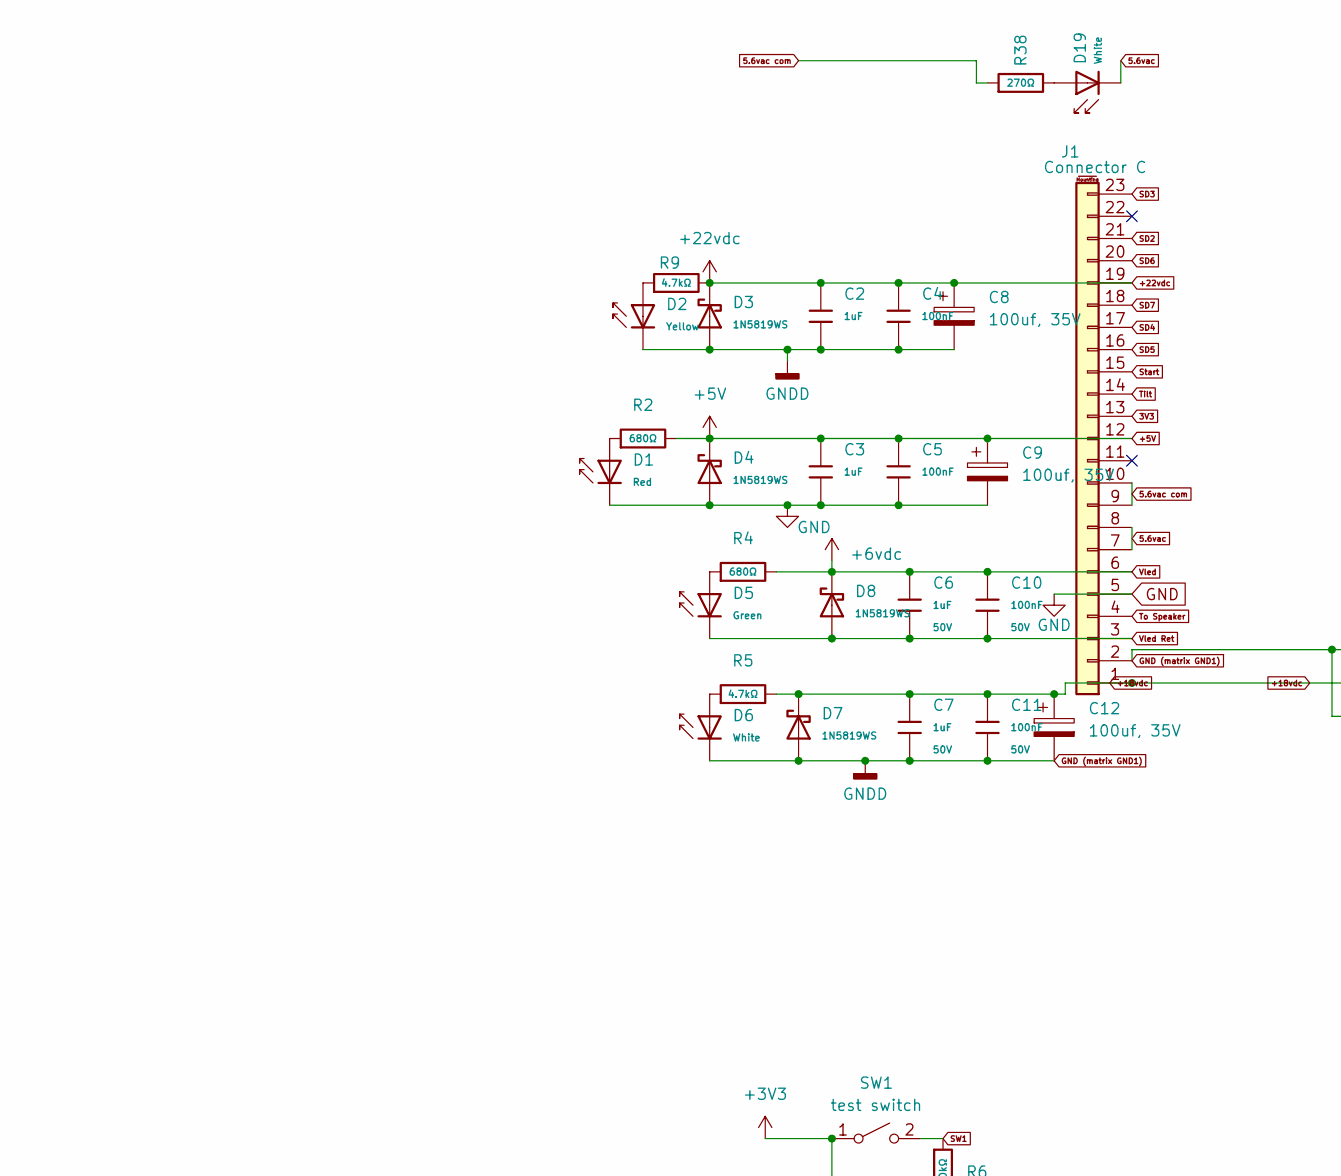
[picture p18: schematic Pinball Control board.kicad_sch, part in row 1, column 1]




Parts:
C1, C2, C3, C6, C7, C13: 1uF; C_0805; Voltage Rated 50V; Tolerance ±10%; Part CL21B105KBFNNNE; LCSC C28323
C4, C5, C10, C11, C14, C15, C19, C20, C21, C22, C23: 100nF; C_0805; Voltage Rated 50V; Tolerance ±10%; Part CC0805KRX7R9BB104; LCSC C49678
C8, C9, C12: 100uf, 35V; CP_Radial_D6.3mm_P2.50mm; LCSC C122240
D1, D21, D22, D23, D24, D25: Red; D_0805; Forward Voltage (VF) 1.6V~2.6V; Part NCD0805R1; LCSC C84256
D2: Yellow; D_0805; Part KT-0805Y; LCSC C2296
D3, D4, D7, D8: 1N5819WS; D_SOD-323; Forward Voltage (Vf@If) 600mV@1A; Reverse Voltage (Vr) 40V; Part 1N5819WS; LCSC C191023
D5: Green; D_0805; Part KT-0805G; LCSC C2297
D6, D19: White; D_0805; Part KT-0805W; LCSC C34499
D9, D11, D13, D15, D17: US1M; D_SMA; Forward Voltage (Vf@If) 1.65V@1A; Reverse Voltage (Vr) 1kV; Part US1M; LCSC C412437
D10, D12, D14, D16, D18: SMCJ30CA; D_SMC; Part SMCJ30CA; LCSC C19077607
H1, H2, H3, H4: MountingHole; MountingHole_3.5mm_Pad
J1: Connector C; CONN_SDA-41792_M450_23_MOL
J3: B4B-XH-A; JST_EH_B4B-EH-A_1x04_P2.50mm_Vertical; PARTREV 7/4/21
J4, J5: Conn_01x10_Pin; PinHeader_1x10_P2.54mm_Vertical
Q1, Q2, Q3, Q4, Q5, Q7, Q9, Q11, Q13, Q15: BSS138; Q_SOT-23; Part BSS138; LCSC C7420339
Q6, Q8, Q10, Q12, Q14: BSS84; Q_SOT-23; Part BSS84; LCSC C7420340
Q16, Q17, Q18, Q19, Q20: IRFR5410; TO-252-2; Manufacturer_Part_Number IRFR5410TRPBF
R1, R8, R34, R37, R50, R51, R52: 2.4kΩ; R_0805; Overload Voltage (Max) 150V; Tolerance ±1%; Part 0805W8F2401T5E; LCSC C17526
R2, R4: 680Ω; R_0805; Overload Voltage (Max) 150V; Tolerance ±1%; Part 0805W8F6800T5E; LCSC C17798
R5, R9: 4.7kΩ; R_0805; Overload Voltage (Max) 150V; Tolerance ±1%; Part 0805W8F4701T5E; LCSC C17673
R6, R7, R14, R15, R16, R17, R18, R19, R20, R21, R22, R23, R29, R30, R31, R32, R33: 10kΩ; R_0805; Overload Voltage (Max) 150V; Tolerance ±1%; Part 0805W8F1002T5E; LCSC C17414
R24, R25, R26, R27, R28: 56Ω; R_0805; Overload Voltage (Max) 150V; Tolerance ±1%; Part 0805W8F560JT5E; LCSC C17757
R38: 270Ω; R_0805; Overload Voltage (Max) 150V; Tolerance ±1%; Part 0805W8F2700T5E; LCSC C17590
SW1, SW2: test switch; Slide Sw LCSC#C7498220; LCSC C7498220

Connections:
3V3: J1.13, J4.8, J5.1
5.6vac: D19.1, J1.7, J1.8
5.6vac com: J1.9, J1.10, R38.1
+3V3: SW1.1 (A), SW2.1 (A)
+5V: C3.1, C5.1, C9.1, D4.1, J1.12, J4.6, J4.7, R2.2
+18vdc: C7.1, C11.1, C12.1, D7.1, J1.1, J3.2, J3.3, R5.2
+22vdc: C2.1, C4.1, C8.1, D3.1, D9.1, D11.1, D13.1, D15.1, D17.1, J1.19, Q6.2 (S), Q8.2 (S), Q10.2 (S), Q12.2 (S), Q14.2 (S), Q16.3 (S), Q17.3 (S), Q18.3 (S), Q19.3 (S), Q20.3 (S), R9.2, R19.2, R20.2, R21.2, R22.2, R23.2; also elsewhere on the board
GND: C1.2, C3.2, C5.2, C9.2, C13.2, C14.2, C15.2, D1.1, D4.2, J1.5, J4.4, J4.5, R1.1, R6.2, R7.2, R8.1
GND (matrix GND1): C2.2, C4.2, C7.2, C8.2, C11.2, C12.2, C19.2, C20.2, C21.2, C22.2, C23.2, D2.1, D3.2, D6.1, D7.2, D10.1, D12.1, D14.1, D16.1, D18.1, D21.2, D22.2, D23.2, D24.2, D25.2, J1.2, J3.1, J3.4, Q1.2 (S), Q2.2 (S), Q3.2 (S), Q4.2 (S), Q5.2 (S), Q7.2 (S), Q9.2 (S), Q11.2 (S), Q13.2 (S), Q15.2 (S), R14.1, R15.1, R16.1, R17.1, R18.1, R29.1, R30.1, R31.1, R32.1, R33.1
unnamed: D1.2, R2.1
unnamed 10: D2.2, R9.1; also elsewhere on the board
unnamed: D5.2, R4.1
unnamed: D6.2, R5.1
unnamed: D19.2, R38.2
unnamed: D21.1, R34.1
unnamed: D22.1, R37.1
unnamed: D23.1, R50.1
unnamed: D24.1, R51.1
unnamed: D25.1, R52.1
unnamed: Q1.3 (D), Q6.1 (G), Q7.1 (G), R19.1
unnamed: Q2.3 (D), Q8.1 (G), Q9.1 (G), R20.1
unnamed: Q6.3 (D), Q7.3 (D), R24.1
unnamed: Q8.3 (D), Q9.3 (D), R25.1
unnamed: Q10.3 (D), Q11.3 (D), R26.1
unnamed: Q3.3 (D), Q10.1 (G), Q11.1 (G), R21.1
unnamed: Q12.3 (D), Q13.3 (D), R27.1
unnamed: Q4.3 (D), Q12.1 (G), Q13.1 (G), R22.1
unnamed: Q14.3 (D), Q15.3 (D), R28.1
unnamed: Q5.3 (D), Q14.1 (G), Q15.1 (G), R23.1
unnamed: Q16.1 (G), R24.2
unnamed: Q17.1 (G), R25.2
unnamed: Q18.1 (G), R26.2
unnamed: Q19.1 (G), R27.2
unnamed: Q20.1 (G), R28.2
S2: J5.2, Q3.1 (G), R16.2
S3: J5.3, Q4.1 (G), R17.2
S4: J5.4, Q5.1 (G), R18.2
S5: J5.5, Q1.1 (G), R14.2
S6: J5.6, Q2.1 (G), R15.2
SD2: C21.1, D13.2, D14.2, J1.21, Q18.2 (D), R31.2, R52.2
SD3: C19.1, D15.2, D16.2, J1.23, Q19.2 (D), R32.2, R51.2
SD4: C22.1, D17.2, D18.2, J1.17, Q20.2 (D), R33.2, R50.2
SD5: C20.1, D9.2, D10.2, J1.16, Q16.2 (D), R29.2, R34.2
SD6: C23.1, D11.2, D12.2, J1.20, Q17.2 (D), R30.2, R37.2
SD7: J1.18
SW1: J5.7, R6.1, SW1.2 (B)
SW2: J5.8, R7.1, SW2.2 (B)
Start: C13.1, C15.1, J1.15, J4.10, R8.2
Tilt: C1.1, C14.1, J1.14, J4.9, R1.2
To Speaker: J1.4, J4.1
Vled: C6.1, C10.1, D8.1, J1.6, J4.3, R4.2
Vled Ret: C6.2, C10.2, D5.1, D8.2, J1.3, J4.2

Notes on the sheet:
BOARD TO BOARD


Board: 2 copper layers, 87.1 x 100.0 mm, 108 parts (0 on the bottom side), 51 nets.

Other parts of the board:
R3: 4.7Ω; R_0805

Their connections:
+22vdc: R3.2; also elsewhere on the board
unnamed 10: R3.1; also elsewhere on the board

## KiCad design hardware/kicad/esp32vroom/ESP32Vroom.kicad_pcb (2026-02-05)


Board: 2 copper layers, 379.7 x 203.4 mm, 192 parts (1 on the bottom side), 128 nets.

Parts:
C1, C2, C3, C4, C5, C6, C7, C8, C9, C16: 0.1uf 50v; C_Axial_L3.8mm_D2.6mm_P10.00mm_Horizontal
C10, C21: 22uf 25v; CP_Radial_D5.0mm_P2.00mm
C11, C12, C13, C14: 100nf; C_Disc_D6.0mm_W4.4mm_P5.00mm
C15: 100uf 16v; C_Radial_D6.3mm_H11.0mm_P2.50mm
C17: 5uf; CP_Radial_D8.0mm_P2.50mm
C18: 500uf; CP_Radial_D8.0mm_P3.50mm
C19: 0.1uf; C_Rect_L7.0mm_W3.5mm_P5.00mm
D1, D2, D3, D4, D5: P6KE30A; D_DO-15_P12.70mm_Horizontal
D6, D7, D8, D9, D10, D11, D12, D13: P6KE20A; D_DO-15_P12.70mm_Horizontal
D14, D15, D16, D17, D18: P6KE6.8A; D_DO-15_P12.70mm_Horizontal
D19, D20, D21, D22: 1N5819; D_DO-41_SOD81_P10.16mm_Horizontal
D25, D27, D28, D34, D35, D36, D37, D38, D39, D40, D41, D42, D43, D44: 1N4001; D_DO-41_SOD81_P10.16mm_Horizontal
D29, D30, D31, D32, D33, D53, D55: 1N4148; D_DO-35_SOD27_P7.62mm_Horizontal
D45, D46, D47, D48, D49, D50, D51, D52, D54, D56, D57, D58, D59, D60, D61, D62, D63, D64: UF4007; D_DO-41_SOD81_P10.16mm_Horizontal
J4: Connector_esp32_1x15; PinSocket_1x15_P2.54mm_Vertical
J10: J 10
J12: Connector C; CONN_SDA-41792_M450_23_MOL
JD2: connector "d"; Connector D
L3, L4, L5, L6, L7: IRLZ44NPBF; TO-220-3_Vertical
LED7: Display lite; LED_D5.0mm_IRBlack
LED9: Player 1; LED_D5.0mm_IRBlack
LED10: Player 2; LED_D5.0mm_IRBlack
LED11: Player 3; LED_D5.0mm_IRBlack
LED12: Player 4; LED_D5.0mm_IRBlack
LED13: status; LED_D5.0mm_IRBlack
LED14: Ball 1; LED_D5.0mm_IRBlack
LED15: Ball 2; LED_D5.0mm_IRBlack
LED16: Ball 3; LED_D5.0mm_IRBlack
LED17: Ball 4; LED_D5.0mm_IRBlack
LED18: Ball 5; LED_D5.0mm_IRBlack
LED19: Game Over; LED_D5.0mm_IRBlack
LED21: Fail; LED_D5.0mm_IRBlack
M1, M2, M3, M4, M5, M6, M7, M8: IRLZ44NPBF; TO-220-3_Vertical
R1: 10k; Potentiometer_Bourns_PTV09A-1_Single_Vertical
R4, R5, R6, R7, R8, R9, R10, R11, R12, R13, R14: 680; R_Axial_DIN0207_L6.3mm_D2.5mm_P7.62mm_Horizontal
R15: 270; R_Axial_DIN0207_L6.3mm_D2.5mm_P7.62mm_Horizontal
R17, R21: 10k; R_Axial_DIN0204_L3.6mm_D1.6mm_P7.62mm_Horizontal
R19, R20: 470; R_Axial_DIN0207_L6.3mm_D2.5mm_P7.62mm_Horizontal
R57, R58, R59, R60, R61, R70, R72, R74, R76, R78, R80, R82, R84, R86, R88, R90, R92, R94, R96, R98, R100, R102, R104: 10k; R_Axial_DIN0207_L6.3mm_D2.5mm_P7.62mm_Horizontal
R62, R63, R64, R65: 2k; R_Axial_DIN0207_L6.3mm_D2.5mm_P7.62mm_Horizontal
R66, R67: 4.7k; R_Axial_DIN0207_L6.3mm_D2.5mm_P7.62mm_Horizontal
R68: 2.7; R_Axial_DIN0207_L6.3mm_D2.5mm_P10.16mm_Horizontal
R69, R71, R73, R75, R77, R79, R81, R83, R85, R87, R89, R91, R93, R95, R97, R99, R101, R103: 220; R_Axial_DIN0207_L6.3mm_D2.5mm_P7.62mm_Horizontal
S2, S3, S4, S5, S6: IRLZ44NPBF; TO-220-3_Vertical
SW1, SW2: test switch; SW_GF-123-0054
U1: 74HC595; DIP-16_W7.62mm_LongPads
U2: PCA9548ADB; Adafruit I2C mux
U4: LM384; DIP-14_W7.62mm
U6, U7, U8, U9, U10: 0.96 OLED display ssd1306; ).96 inOLED display SSD1306
r16: Tilt; LED_D5.0mm_IRBlack

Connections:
5.6vac: D25.2 (A), J12.7, J12.8
5.6vac com: J12.9, J12.10, R15.2
18vdc Ret: J12.2, M1.3 (S), M2.3 (S), M3.3 (S), M4.3 (S), M5.3 (S), M6.3 (S), M7.3 (S), M8.3 (S)
+3V3: C1.1, J10.16 (VDD_3V3), R57.1, R66.1, R67.1
+5V: C21.1, D22.1 (K), J4.1 (Vin), J12.12, R17.1, R19.1, R20.2, R21.1, U1.16 (VCC), U2.1 (Vcc), U6.2 (VCC), U7.2 (VCC), U8.2 (VCC), U9.2 (VCC), U10.2 (VCC)
+18vdc: C10.1, C16.1, D20.1 (K), D45.1 (K), D46.1 (K), D47.1 (K), D48.1 (K), D49.1 (K), D50.1 (K), D51.1 (K), D52.1 (K), J12.1, U4.14 (VS)
+22vdc: D21.1 (K), D54.1 (K), D56.1 (K), D57.1 (K), D58.1 (K), D59.1 (K), J12.19
Audio: C15.2, D33.1 (K), J4.8 (GPIO25)
GND: C1.2, C2.2, C3.2, C4.2, C5.2, C6.2, C7.2, C8.2, C9.2, C10.2, C11.2, C12.2, C13.2, C14.2, C16.2, C17.2, C19.2, C21.2, D1.2 (A), D2.2 (A), D3.2 (A), D4.2 (A), D5.2 (A), D6.2 (A), D7.2 (A), D8.2 (A), D9.2 (A), D10.2 (A), D11.2 (A), D12.2 (A), D13.2 (A), D14.2 (A), D15.2 (A), D16.2 (A), D17.2 (A), D18.2 (A), D19.2 (A), D20.2 (A), D21.2 (A), D22.2 (A), D29.2 (A), D30.2 (A), D31.2 (A), D32.2 (A), D33.2 (A), J4.2 (GND), J10.17 (GND), J12.5, L3.3 (S), L4.3 (S), L5.3 (S), L6.3 (S), L7.3 (S), R1.3, R62.1, R63.1, R64.1, R65.1, R70.2, R72.2, R74.2, R76.2, R78.2, R80.2, R82.2, R84.2, R86.2, R88.2, R90.2, R92.2, R94.2, R96.2, R98.2, R100.2, R102.2, R104.2, S2.3 (S), S3.3 (S), S4.3 (S), S5.3 (S), S6.3 (S), U1.8 (GND), U1.13 (~OE), U2.2 (Gnd), U2.6 (A0), U2.7 (A1), U2.8 (A2), U4.2 (+), U4.3 (GND), U4.4 (GND), U4.5 (GND), U4.7 (GND), U4.10 (GND), U4.11 (GND), U4.12 (GND), U6.1 (GND), U7.1 (GND), U8.1 (GND), U9.1 (GND), U10.1 (GND)
I2C SCL: J10.29 (I2C-SCL), R66.2, U2.3 (SDA_IN)
I2C SDA: J10.26 (I2C_SDA), R67.2, U2.4 (SCL_IN)
L3: J4.5 (GPIO14), R95.2
L4: J4.6 (GPIO27), R97.2
L5: J4.7 (GPIO26), R99.2
L6: J4.9 (GPIO33), R101.2
L7: J4.10 (GPIO32), R103.2
LD3: D14.1 (K), D60.2 (A), JD2.20, L3.2 (D), R8.2, R14.2
LD4: D15.1 (K), D61.2 (A), JD2.23, L4.2 (D), R4.2, R9.2
LD5: D16.1 (K), D62.2 (A), JD2.24, L5.2 (D), R5.2, R10.2
LD6: D17.1 (K), D63.2 (A), JD2.22, L6.2 (D), R6.2, R11.2
LD7: D18.1 (K), D64.2 (A), JD2.21, L7.2 (D), R7.2, R12.2, R13.2
M1: J10.18 (GPIO15), R69.2
M2: J10.21 (GPIO16), R71.2
M3: J10.22 (GPIO17), R73.2
M4: J10.23 (GPIO5), R75.2
M5: J10.24 (GPIO18), R77.2
M6: J10.25 (GPIO19), R79.2
M7: J10.30 (GPIO23), R81.2
M8: J4.3 (GPIO13), R83.2
MX1: C2.1, D6.1 (K), D44.2 (A), D45.2 (A), D53.2 (A), JD2.1, M1.2 (D)
MX2: C3.1, D7.1 (K), D46.2 (A), D55.2 (A), JD2.2, JD2.3, M2.2 (D)
MX3: C4.1, D8.1 (K), D47.2 (A), JD2.10, JD2.11, M3.2 (D)
MX4: C5.1, D9.1 (K), D48.2 (A), JD2.12, JD2.13, M4.2 (D)
MX5: C6.1, D10.1 (K), D27.2 (A), D49.2 (A), JD2.15, JD2.16, M5.2 (D)
MX6: C7.1, D11.1 (K), D28.2 (A), D43.2 (A), D50.2 (A), JD2.17, JD2.18, M6.2 (D)
MX7: C8.1, D12.1 (K), D38.2 (A), D39.2 (A), D40.2 (A), D41.2 (A), D42.2 (A), D51.2 (A), JD2.19, M7.2 (D)
MX8: C9.1, D13.1 (K), D34.2 (A), D35.2 (A), D36.2 (A), D37.2 (A), D52.2 (A), M8.2 (D)
unnamed: C15.1, R1.1
unnamed: C18.1, R68.1, U4.8
unnamed: C19.1, R68.2
unnamed: D25.1 (K), LED7.1 (K)
unnamed: D27.1 (K), SW1.1 (A)
unnamed: D28.1 (K), SW2.1 (A)
unnamed: D34.1 (K), LED9.2 (A)
unnamed: D35.1 (K), LED10.2 (A)
unnamed: D36.1 (K), LED11.2 (A)
unnamed: D37.1 (K), LED12.2 (A)
unnamed: D38.1 (K), r16.2 (A)
unnamed: D39.1 (K), LED14.2 (A)
unnamed: D40.1 (K), LED15.2 (A)
unnamed: D41.1 (K), LED16.2 (A)
unnamed: D42.1 (K), LED17.2 (A)
unnamed: D43.1 (K), LED18.2 (A)
unnamed: D44.1 (K), LED19.2 (A)
unnamed: D53.1 (K), J12.14
unnamed: D55.1 (K), J12.15
unnamed: J4.15 (EN_/_RESET), R57.2
unnamed: L3.1 (G), R95.1, R96.1
unnamed: L4.1 (G), R97.1, R98.1
unnamed: L5.1 (G), R99.1, R100.1
unnamed: L6.1 (G), R101.1, R102.1
unnamed: L7.1 (G), R103.1, R104.1
unnamed: LED7.2 (A), R15.1
unnamed: LED9.1 (K), R4.1
unnamed: LED10.1 (K), R5.1
unnamed: LED11.1 (K), R6.1
unnamed: LED12.1 (K), R7.1
unnamed: LED13.2 (A), U1.5 (QF)
unnamed: LED13.1 (K), R19.2
unnamed: LED14.1 (K), R9.1
unnamed: LED15.1 (K), R10.1
unnamed: LED16.1 (K), R11.1
unnamed: LED17.1 (K), R12.1
unnamed: LED18.1 (K), R13.1
unnamed: LED19.1 (K), R14.1
unnamed: LED21.2 (A), U1.6 (QG)
unnamed: LED21.1 (K), R20.1
unnamed: M1.1 (G), R69.1, R70.1
unnamed: M2.1 (G), R71.1, R72.1
unnamed: M3.1 (G), R73.1, R74.1
unnamed: M4.1 (G), R75.1, R76.1
unnamed: M5.1 (G), R77.1, R78.1
unnamed: M6.1 (G), R79.1, R80.1
unnamed: M7.1 (G), R81.1, R82.1
unnamed: M8.1 (G), R83.1, R84.1
unnamed: R85.1, R86.1, S2.1 (G)
unnamed: R87.1, R88.1, S3.1 (G)
unnamed: R89.1, R90.1, S4.1 (G)
unnamed: R91.1, R92.1, S5.1 (G)
unnamed: R93.1, R94.1, S6.1 (G)
unnamed: R21.2, U1.10 (~SRCLR)
unnamed: R17.2, U2.5 (Reset)
unnamed: R1.2, U4.6 (-)
unnamed: C17.1, U4.1 (BYPASS)
unnamed: R8.1, r16.1 (K)
S2: R85.2, U1.15 (QA)
S3: R87.2, U1.1 (QB)
S4: R89.2, U1.2 (QC)
S5: R91.2, U1.3 (QD)
S6: R93.2, U1.4 (QE)
SCL_0: U2.10 (SCL0), U10.3 (SLC)
SCL_1: U2.12 (SCL1), U9.3 (SLC)
SCL_2: U2.14 (SCL2), U8.3 (SLC)
SCL_3: U2.16 (SCL3), U7.3 (SLC)
SCL_4: U2.18 (SCL4), U6.3 (SLC)
SD2: D5.1 (K), D54.2 (A), J12.21, S2.2 (D)
SD3: D4.1 (K), D56.2 (A), J12.23, S3.2 (D)
SD4: D3.1 (K), D57.2 (A), J12.17, S4.2 (D)
SD5: D2.1 (K), D58.2 (A), J12.16, S5.2 (D)
SD6: D1.1 (K), D59.2 (A), J12.20, S6.2 (D)
SDA_0: U2.9 (SDA0), U10.4 (SDA)
SDA_1: U2.11 (SDA1), U9.4 (SDA)
SDA_2: U2.13 (SDA2), U8.4 (SDA)
SDA_3: U2.15 (SDA3), U7.4 (SDA)
SDA_4: U2.17 (SDA4), U6.4 (SDA)
SW1: D29.1 (K), J4.11 (GPIO35), R58.2
SW2: D30.1 (K), J4.12 (GPIO34), R59.2
SW3: D31.1 (K), J4.13 (GPIO39), R60.2
SW4: D32.1 (K), J4.14 (GPIO36), R61.2
SW_0: C11.1, JD2.7, R58.1, R62.2
SW_1: C12.1, J12.13, JD2.6, R59.1, R63.2, SW1.2 (B), SW2.2 (B)
SW_2: C13.1, JD2.5, R60.1, R64.2
SW_3: C14.1, JD2.4, R61.1, R65.2
To Speaker: C18.2, J12.4
Vled: D19.1 (K), D60.1 (K), D61.1 (K), D62.1 (K), D63.1 (K), D64.1 (K), J12.6
a0: J4.4 (GPIO12), U1.14 (SER)
a1: J10.20 (GPIO4), U1.12 (RCLK)
a2: J10.19 (GPIO2), U1.11 (SRCLK)

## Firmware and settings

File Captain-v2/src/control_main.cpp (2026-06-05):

#include <Arduino.h>
#include "freertos/FreeRTOS.h"
#include "freertos/queue.h"
#include "freertos/task.h"
#include <Wire.h>
#include <SPI.h>
#include <WiFi.h>
#include <ArduinoOTA.h>
#include <Adafruit_NeoPixel.h>
#include <driver/i2s.h>
#include "captain_protocol.h"
#include "captain_mapping.h"
#include "solenoid_gpio_config.h"
#include "direct_input_config.h"
#include "audio_i2s_config.h"
#include "i2c_bus_config.h"
#include "external_flash_config.h"
#include "ota_config.h"
#include "headbox_attract_config.h"
#include "headbox_595_config.h"
#include "displays.h"

#ifndef CAPTAIN_BUILD_GIT_HASH
#define CAPTAIN_BUILD_GIT_HASH "unknown"
#endif

#ifndef CAPTAIN_BUILD_GIT_STATE
#define CAPTAIN_BUILD_GIT_STATE "unknown"
#endif

namespace {
constexpr uint32_t POLL_MS = 30;
constexpr uint32_t DIRECT_INPUT_POLL_MS = 5;
constexpr uint8_t DIRECT_INPUT_DEBOUNCE_TICKS = 3;
constexpr uint8_t HEARTBEAT_PIN = 15;
constexpr uint32_t HEARTBEAT_INTERVAL_MS = 500;
constexpr bool HEARTBEAT_IS_WS2812 = true;
constexpr uint16_t GPIO15_WS2812_CHAIN_PIXELS = 301;  // D1 + external strip chain
struct GameplayLedSegment {
    uint16_t startPixel;
    uint16_t pixelCount;
};
struct GameplayLedRange {
    uint16_t startPixel;
    uint16_t endPixelInclusive;
};
struct GameplayGraphicZone {
    const GameplayLedRange* ranges;
    uint8_t rangeCount;
};
constexpr uint8_t GAMEPLAY_LED_SEGMENT_COUNT = 15;
// Physical strip map (pixel 0 reserved for onboard first pixel, strip starts at pixel 1).
constexpr GameplayLedSegment GAMEPLAY_LED_SEGMENTS[GAMEPLAY_LED_SEGMENT_COUNT] = {
    {1, 11},
    {12, 11},
    {23, 30},
    {53, 32},
    {85, 30},
    {115, 23},
    {138, 9},
    {147, 22},
    {169, 26},
    {195, 18},
    {213, 18},
    {231, 15},
    {246, 19},
    {265, 8},
    {273, 28},
};
// Graphic zones from playfield artwork mapping.
constexpr GameplayLedRange GAMEPLAY_GRAPHIC_ZONE_1[] = {
    {175, 179},
    {245, 249},
};
constexpr GameplayLedRange GAMEPLAY_GRAPHIC_ZONE_2[] = {
    {175, 179},
    {230, 249},
    {1, 8},
};
constexpr GameplayLedRange GAMEPLAY_GRAPHIC_ZONE_3[] = {
    {14, 30},
};
constexpr GameplayLedRange GAMEPLAY_GRAPHIC_ZONE_4[] = {
    {40, 60},
};
constexpr GameplayLedRange GAMEPLAY_GRAPHIC_ZONE_5[] = {
    {184, 199},
    {256, 264},
};
constexpr GameplayLedRange GAMEPLAY_GRAPHIC_ZONE_6[] = {
    {272, 293},
    {212, 230},
    {1, 4},
};
constexpr GameplayLedRange GAMEPLAY_GRAPHIC_ZONE_6A[] = {
    {275, 277},
    {215, 217},
};
constexpr GameplayLedRange GAMEPLAY_GRAPHIC_ZONE_6B[] = {
    {277, 280},
    {218, 221},
};
constexpr GameplayLedRange GAMEPLAY_GRAPHIC_ZONE_6C[] = {
    {281, 282},
    {222, 224},
};
constexpr GameplayLedRange GAMEPLAY_GRAPHIC_ZONE_6D[] = {
    {282, 286},
    {225, 227},
};
constexpr GameplayGraphicZone GAMEPLAY_GRAPHIC_ZONES[] = {
    {GAMEPLAY_GRAPHIC_ZONE_1, static_cast<uint8_t>(sizeof(GAMEPLAY_GRAPHIC_ZONE_1) / sizeof(GAMEPLAY_GRAPHIC_ZONE_1[0]))},
    {GAMEPLAY_GRAPHIC_ZONE_2, static_cast<uint8_t>(sizeof(GAMEPLAY_GRAPHIC_ZONE_2) / sizeof(GAMEPLAY_GRAPHIC_ZONE_2[0]))},
    {GAMEPLAY_GRAPHIC_ZONE_3, static_cast<uint8_t>(sizeof(GAMEPLAY_GRAPHIC_ZONE_3) / sizeof(GAMEPLAY_GRAPHIC_ZONE_3[0]))},
    {GAMEPLAY_GRAPHIC_ZONE_4, static_cast<uint8_t>(sizeof(GAMEPLAY_GRAPHIC_ZONE_4) / sizeof(GAMEPLAY_GRAPHIC_ZONE_4[0]))},
    {GAMEPLAY_GRAPHIC_ZONE_5, static_cast<uint8_t>(sizeof(GAMEPLAY_GRAPHIC_ZONE_5) / sizeof(GAMEPLAY_GRAPHIC_ZONE_5[0]))},
    {GAMEPLAY_GRAPHIC_ZONE_6, static_cast<uint8_t>(sizeof(GAMEPLAY_GRAPHIC_ZONE_6) / sizeof(GAMEPLAY_GRAPHIC_ZONE_6[0]))},
    {GAMEPLAY_GRAPHIC_ZONE_6A, static_cast<uint8_t>(sizeof(GAMEPLAY_GRAPHIC_ZONE_6A) / sizeof(GAMEPLAY_GRAPHIC_ZONE_6A[0]))},
    {GAMEPLAY_GRAPHIC_ZONE_6B, static_cast<uint8_t>(sizeof(GAMEPLAY_GRAPHIC_ZONE_6B) / sizeof(GAMEPLAY_GRAPHIC_ZONE_6B[0]))},
    {GAMEPLAY_GRAPHIC_ZONE_6C, static_cast<uint8_t>(sizeof(GAMEPLAY_GRAPHIC_ZONE_6C) / sizeof(GAMEPLAY_GRAPHIC_ZONE_6C[0]))},
    {GAMEPLAY_GRAPHIC_ZONE_6D, static_cast<uint8_t>(sizeof(GAMEPLAY_GRAPHIC_ZONE_6D) / sizeof(GAMEPLAY_GRAPHIC_ZONE_6D[0]))},
};
constexpr uint8_t GAMEPLAY_GRAPHIC_ZONE_COUNT = static_cast<uint8_t>(sizeof(GAMEPLAY_GRAPHIC_ZONES) / sizeof(GAMEPLAY_GRAPHIC_ZONES[0]));
constexpr uint8_t GAMEPLAY_LED_MAX_CHANNEL = 96;
constexpr uint16_t GAMEPLAY_LED_CURRENT_LIMIT_MA = 1200;
constexpr bool HEARTBEAT_ENABLE_IN_ATTRACT = false;
constexpr bool HEARTBEAT_ENABLE_IN_SERVE_BALL = false;
constexpr bool HEARTBEAT_ENABLE_IN_BALL_IN_PLAY = false;
constexpr bool HEARTBEAT_ENABLE_IN_BONUS_COUNTDOWN = false;
constexpr bool HEARTBEAT_ENABLE_IN_GAME_OVER = false;
constexpr bool HEARTBEAT_FEATURE_ENABLED =
    HEARTBEAT_ENABLE_IN_ATTRACT ||
    HEARTBEAT_ENABLE_IN_SERVE_BALL ||
    HEARTBEAT_ENABLE_IN_BALL_IN_PLAY ||
    HEARTBEAT_ENABLE_IN_BONUS_COUNTDOWN ||
    HEARTBEAT_ENABLE_IN_GAME_OVER;
constexpr bool GAMEPLAY_LED_FEEDBACK_ENABLED = true;
constexpr uint32_t GAMEPLAY_LED_PULSE_MS = 80;
constexpr uint32_t GAMEPLAY_LED_ANIM_STEP_MS = 120;
constexpr uint32_t MATRIX_DIAG_POLL_MS = 250;
constexpr uint32_t MATRIX_LINK_TIMEOUT_MS = 1000;
constexpr uint32_t MATRIX_LINK_SUMMARY_MS = 1000;
constexpr uint32_t MATRIX_INIT_RETRY_MS = 1000;
constexpr uint32_t MATRIX_LAMP_KEEPALIVE_MS = 250;
constexpr bool MATRIX_TRACE_ENABLED = false;
constexpr uint32_t MATRIX_TRACE_WINDOW_MS = 15000;
constexpr uint32_t MATRIX_SWITCH_LOG_DEBOUNCE_MS = 250;
constexpr uint32_t MATRIX_SWITCH_LOG_REPORT_MS = 1000;
constexpr uint16_t MATRIX_SWITCH_LOG_MAX_PER_REPORT = 12;
constexpr uint8_t MATRIX_SWITCH_CONFIRM_POLLS = 5;
constexpr bool MATRIX_SWITCH_BITS_ACTIVE_HIGH = false;
// Diagnostic mode: force matrix lamps off to isolate switch mapping from lamp-scan coupling.
// Disabled for normal solenoid bring-up/gameplay.
constexpr bool MATRIX_SWITCH_MAPPING_MODE = false;
constexpr bool START_BUTTON_SOLENOID_TEST_ENABLED = false;
constexpr bool MATRIX_SWITCH_SOLENOIDS_ENABLED = true;
constexpr uint8_t S20_OUTHOLE_SWITCH_ROW = 0;
constexpr uint8_t S20_OUTHOLE_SWITCH_COL = 0;
constexpr uint32_t S20_OUTHOLE_RETRIGGER_COOLDOWN_MS = 50;
// Temporary S2 safety limiter: prevent outhole retrigger loops while eject force is weak.
constexpr uint32_t S2_RETRIGGER_COOLDOWN_MS = 1500;
constexpr uint32_t S2_WINDOW_MS = 10000;
constexpr uint8_t S2_MAX_FIRES_PER_WINDOW = 3;
constexpr uint8_t S2_MAX_FIRES_PER_BALL = 5;
// Real gameplay: no more than 2-3 switches can close simultaneously (ball hits multiple targets).
// Scan transients appear as 5-28 edges per poll. Threshold of 4 passes genuine multi-switch
// events while blocking all observed scan-induced bursts.
constexpr uint8_t MATRIX_MAX_RISING_EDGES_PER_POLL = 4;
constexpr BaseType_t CONTROL_TASK_CORE = 1;
constexpr BaseType_t AUDIO_TASK_CORE = 0;
constexpr UBaseType_t CONTROL_TASK_PRIORITY = 3;
constexpr UBaseType_t AUDIO_TASK_PRIORITY = 2;
constexpr uint32_t CONTROL_TASK_STACK_BYTES = 8192;
constexpr uint32_t AUDIO_TASK_STACK_BYTES = 6144;
constexpr uint8_t AUDIO_QUEUE_LENGTH = 16;

struct AudioToneEvent {
    uint16_t frequencyHz;
    uint16_t durationMs;
};

enum CaptainGameMode : uint8_t {
    GAME_MODE_ATTRACT = 0,
    GAME_MODE_SERVE_BALL,
    GAME_MODE_BALL_IN_PLAY,
    GAME_MODE_BONUS_COUNTDOWN,
    GAME_MODE_GAME_OVER
};

struct CaptainGameplayState {
    CaptainGameMode mode = GAME_MODE_ATTRACT;
    uint32_t score = 0;
    uint16_t bonus = 1000;
    uint8_t bonusMultiplier = 1;
    uint8_t currentBall = 0;
    bool ballInPlay = false;
    bool laneAComplete = false;
    bool laneBComplete = false;
    bool laneCComplete = false;
    bool laneDComplete = false;
    bool target1Complete = false;
    bool target2Complete = false;
    bool target3Complete = false;
    bool samePlayerLit = false;
    uint32_t lastBonusStepMs = 0;
};

constexpr uint32_t BONUS_COUNTDOWN_STEP_MS = 200;
constexpr uint16_t GAMEPLAY_BONUS_START = 1000;
constexpr uint16_t GAMEPLAY_BONUS_MAX = 10000;

uint32_t displayScore = 0;
uint32_t lastDisplayedScore = UINT32_MAX;
uint32_t lastDisplayUpdate = 0;
uint8_t previousSwitchBits[CAPTAIN_SWITCH_BYTES] = {};
uint8_t stableMatrixSwitchBits[CAPTAIN_SWITCH_BYTES] = {};
uint8_t candidateMatrixSwitchBits[CAPTAIN_SWITCH_BYTES] = {};
uint8_t matrixSwitchConfirmTicks[CAPTAIN_SWITCH_ROWS * CAPTAIN_SWITCH_COLS] = {};
uint8_t lastMatrixLampRows[CAPTAIN_LAMP_ROWS] = {};
bool matrixLampFramePrimed = false;
uint32_t lastMatrixLampWriteMs = 0;
uint16_t headboxPattern = 0;
bool solenoidActive[SOLENOID_COUNT] = {false};
uint32_t solenoidStartedAtMs[SOLENOID_COUNT] = {0};
bool directInputStable[DIRECT_INPUT_COUNT] = {false};
uint8_t directInputDebounceCounter[DIRECT_INPUT_COUNT] = {0};
uint32_t lastDirectInputPollMs = 0;
bool tiltLatched = false;
bool i2sAudioReady = false;
uint32_t i2sWriteCalls = 0;
uint32_t i2sWriteErrors = 0;
uint32_t i2sBytesWrittenTotal = 0;
uint8_t audioBclkPinEffective = CAPTAIN_AUDIO_BCLK_PIN;
uint8_t audioLrckPinEffective = CAPTAIN_AUDIO_LRCK_PIN;
bool heartbeatEnabled = false;
bool heartbeatState = false;
uint32_t lastHeartbeatToggleMs = 0;
Adafruit_NeoPixel heartbeatPixel(GPIO15_WS2812_CHAIN_PIXELS, HEARTBEAT_PIN, NEO_GRB + NEO_KHZ800);
bool gameplayLedPulseActive = false;
uint8_t gameplayLedPulseSegment = 0;
uint32_t gameplayLedPulseUntilMs = 0;
uint32_t gameplayLedLastAnimStepMs = 0;
uint8_t gameplayLedAnimStep = 0;
bool otaReady = false;
bool otaInProgress = false;
uint32_t lastOtaVisualToggleMs = 0;
bool otaVisualState = false;
uint32_t lastHeadboxAttractStepMs = 0;
uint8_t headboxAttractStep = 0;
bool matrixDeviceReady = false;
uint32_t lastMatrixGoodTransactionMs = 0;
uint32_t lastMatrixInitAttemptMs = 0;
uint32_t lastMatrixDiagPollMs = 0;
bool matrixLinkFaulted = false;
uint32_t matrixWriteOkCount = 0;
uint32_t matrixWriteFailCount = 0;
uint32_t matrixReadOkCount = 0;
uint32_t matrixReadFailCount = 0;
uint32_t matrixDiagReadFailCount = 0;
uint32_t matrixDiagWarnCount = 0;
uint32_t lastMatrixLinkSummaryMs = 0;
uint8_t lastRawMatrixSwitch0 = 0;
uint8_t lastRawMatrixSwitch1 = 0;
uint8_t lastRawMatrixSwitch2 = 0;
uint8_t lastRawMatrixSwitch3 = 0;
uint8_t lastMatrixSwitch0 = 0;
uint8_t lastMatrixSwitch1 = 0;
uint8_t lastMatrixSwitch2 = 0;
uint8_t lastMatrixSwitch3 = 0;
bool matrixSwitch0Seen = false;
bool matrixDiagFaulted = false;
uint32_t matrixSwitchLogSuppressedDebounce = 0;
uint32_t matrixSwitchLogSuppressedRate = 0;
uint32_t matrixSwitchSuppressedBurst = 0;
uint32_t matrixSwitchSuppressedLampEcho = 0;
uint32_t matrixTraceSeq = 0;
uint32_t lastMatrixSwitchEdgeLogMs = 0;
uint32_t s20OutholeLastRiseMs = 0;
uint32_t s20OutholeSuppressedSticky = 0;
uint32_t s2SuppressedCooldown = 0;
uint32_t s2SuppressedWindow = 0;
uint32_t s2SuppressedBall = 0;
bool currentSW1Mode = false;  // false = Easy, true = Hard
bool currentSW2Mode = false;  // false = Game, true = Test
uint16_t matrixSwitchLoggedThisWindow = 0;
uint16_t matrixSwitchEdgesThisWindow = 0;
uint32_t matrixSwitchLogWindowStartMs = 0;
uint32_t s2WindowStartMs = 0;
uint32_t s2LastFireMs = 0;
uint8_t s2FiresInWindow = 0;
uint8_t s2FiresThisBall = 0;
CaptainGameplayState gameplayState = {};
QueueHandle_t audioToneQueue = nullptr;
TaskHandle_t controlTaskHandle = nullptr;
TaskHandle_t audioTaskHandle = nullptr;

void resetGameplayStateForNewBall();
void startNewGame();
void startBonusCountdown(uint32_t nowMs);
void updateGameplayState(uint32_t nowMs);
void handleGameplaySwitchHit(uint8_t row, uint8_t col, uint32_t nowMs);
void triggerGameplayLedPulse(uint8_t segment, uint8_t red, uint8_t green, uint8_t blue, uint32_t nowMs);
void updateGameplayLedPulse(uint32_t nowMs);
void updateGameplayLedPattern(uint32_t nowMs);
void setGameplayLedZone(uint8_t segment, uint8_t red, uint8_t green, uint8_t blue);
void setGameplayLedZoneNoShow(uint8_t segment, uint8_t red, uint8_t green, uint8_t blue);
void setGameplayGraphicZoneNoShow(uint8_t graphicZone, uint8_t red, uint8_t green, uint8_t blue);
void clearGameplayLedStripBuffer();
void showGameplayLedStripBuffer();
void applyGameplayLedCurrentLimit(uint16_t pixelCount, uint8_t& red, uint8_t& green, uint8_t& blue);
uint8_t mapSwitchToGameplayLedZone(uint8_t row, uint8_t col);
bool queueTone(uint16_t frequencyHz, uint16_t durationMs) {
    if (!i2sAudioReady || CAPTAIN_AUDIO_GPIO_ONLY_TEST_MODE || audioToneQueue == nullptr) {
        return false;
    }

    AudioToneEvent event = {frequencyHz, durationMs};
    if (xQueueSend(audioToneQueue, &event
        , 0) == pdPASS) {
        return true;
    }
    return false;
}

void updateHeadboxLamps(uint16_t pattern);

bool matrixTraceEnabledNow() {
    return MATRIX_TRACE_ENABLED && millis() <= MATRIX_TRACE_WINDOW_MS;
}

void logMatrixTrace(const char* event,
                    uint8_t reg,
                    const uint8_t* bytes,
                    size_t length) {
    if (!matrixTraceEnabledNow()) {
        return;
    }

    const uint8_t b0 = (length > 0 && bytes != nullptr) ? bytes[0] : 0;
    const uint8_t b1 = (length > 1 && bytes != nullptr) ? bytes[1] : 0;
    const uint8_t b2 = (length > 2 && bytes != nullptr) ? bytes[2] : 0;
    const uint8_t b3 = (length > 3 && bytes != nullptr) ? bytes[3] : 0;
    const uint8_t b4 = (length > 4 && bytes != nullptr) ? bytes[4] : 0;

    Serial.printf("[mx %lu] %s reg=0x%02X len=%u b=[%02X,%02X,%02X,%02X,%02X]\n",
                  static_cast<unsigned long>(matrixTraceSeq++),
                  event,
                  static_cast<unsigned>(reg),
                  static_cast<unsigned>(length),
                  static_cast<unsigned>(b0),
                  static_cast<unsigned>(b1),
                  static_cast<unsigned>(b2),
                  static_cast<unsigned>(b3),
                  static_cast<unsigned>(b4));
}

void recordMatrixTransactionResult(bool ok) {
    const uint32_t now = millis();
    if (ok) {
        lastMatrixGoodTransactionMs = now;
        if (matrixLinkFaulted) {
            matrixLinkFaulted = false;
            Serial.println("Matrix link recovered");
        }
        return;
    }

    if (!matrixLinkFaulted && lastMatrixGoodTransactionMs != 0 && (now - lastMatrixGoodTransactionMs) >= MATRIX_LINK_TIMEOUT_MS) {
        matrixLinkFaulted = true;
        Serial.println("Matrix link fault: transaction timeout exceeded 1000 ms safe window");
    }
}

bool matrixWriteCommandByte(uint8_t value) {
    Wire.beginTransmission(CAPTAIN_MATRIX_I2C_ADDRESS);
    Wire.write(value);
    const bool ok = Wire.endTransmission() == 0;
    recordMatrixTransactionResult(ok);
    return ok;
}

bool matrixWriteRegisters(uint8_t startRegister, const uint8_t* data, size_t len) {
    Wire.beginTransmission(CAPTAIN_MATRIX_I2C_ADDRESS);
    Wire.write(startRegister);
    Wire.write(data, len);
    const bool ok = Wire.endTransmission() == 0;
    logMatrixTrace(ok ? "wr" : "wr_fail", startRegister, data, len);
    recordMatrixTransactionResult(ok);
    return ok;
}

bool matrixReadRegisters(uint8_t startRegister, uint8_t* out, size_t len) {
    Wire.beginTransmission(CAPTAIN_MATRIX_I2C_ADDRESS);
    Wire.write(startRegister);
    if (Wire.endTransmission(false) != 0) {
        logMatrixTrace("rd_ptr_fail", startRegister, nullptr, 0);
        recordMatrixTransactionResult(false);
        return false;
    }

    const size_t received = Wire.requestFrom(static_cast<int>(CAPTAIN_MATRIX_I2C_ADDRESS), static_cast<int>(len));
    if (received != len) {
        logMatrixTrace("rd_len_fail", startRegister, nullptr, received);
        while (Wire.available()) {
            Wire.read();
        }
        recordMatrixTransactionResult(false);
        return false;
    }

    for (size_t index = 0; index < len; index++) {
        out[index] = static_cast<uint8_t>(Wire.read());
    }
    logMatrixTrace("rd", startRegister, out, len);
    recordMatrixTransactionResult(true);
    return true;
}

void initMatrixDevice() {
    const uint32_t now = millis();
    lastMatrixInitAttemptMs = now;

    Wire.beginTransmission(CAPTAIN_MATRIX_I2C_ADDRESS);
    const uint8_t probeError = Wire.endTransmission();

    if (probeError == 0) {
        matrixDeviceReady = true;
        lastMatrixGoodTransactionMs = now;
        matrixLinkFaulted = false;
        Serial.printf("Matrix device ready at 0x%02X (simplified bridge mode, no HT16K33 emulation)\n",
                      CAPTAIN_MATRIX_I2C_ADDRESS);
        return;
    }

    matrixDeviceReady = false;
    Serial.printf("Matrix device missing at 0x%02X (err=%u), retrying...\n",
                  CAPTAIN_MATRIX_I2C_ADDRESS,
                  static_cast<unsigned>(probeError));
}

void logMatrixLinkSummary(uint32_t now) {
    if ((now - lastMatrixLinkSummaryMs) < MATRIX_LINK_SUMMARY_MS) {
        return;
    }

    lastMatrixLinkSummaryMs = now;
    Serial.printf("Matrix link: ready=%u fault=%u wr_ok=%lu wr_fail=%lu rd_ok=%lu rd_fail=%lu diag_warn=%lu raw0=0x%02X raw1=0x%02X raw2=0x%02X raw3=0x%02X sw0=0x%02X sw1=0x%02X sw2=0x%02X sw3=0x%02X sw_edges=%u sw_log=%u sup_db=%lu sup_rate=%lu sup_le=%lu s20_sticky=%lu s2_fire=%u s2_cd=%lu s2_win=%lu s2_ball=%lu\n",
                  matrixDeviceReady ? 1u : 0u,
                  matrixLinkFaulted ? 1u : 0u,
                  static_cast<unsigned long>(matrixWriteOkCount),
                  static_cast<unsigned long>(matrixWriteFailCount),
                  static_cast<unsigned long>(matrixReadOkCount),
                  static_cast<unsigned long>(matrixReadFailCount),
                  static_cast<unsigned long>(matrixDiagWarnCount),
                  static_cast<unsigned>(lastRawMatrixSwitch0),
                  static_cast<unsigned>(lastRawMatrixSwitch1),
                  static_cast<unsigned>(lastRawMatrixSwitch2),
                  static_cast<unsigned>(lastRawMatrixSwitch3),
                  static_cast<unsigned>(lastMatrixSwitch0),
                  static_cast<unsigned>(lastMatrixSwitch1),
                  static_cast<unsigned>(lastMatrixSwitch2),
                  static_cast<unsigned>(lastMatrixSwitch3),
                  static_cast<unsigned>(matrixSwitchEdgesThisWindow),
                  static_cast<unsigned>(matrixSwitchLoggedThisWindow),
                  static_cast<unsigned long>(matrixSwitchLogSuppressedDebounce),
                  static_cast<unsigned long>(matrixSwitchLogSuppressedRate),
                  static_cast<unsigned long>(matrixSwitchSuppressedLampEcho),
                  static_cast<unsigned long>(s20OutholeSuppressedSticky),
                  static_cast<unsigned>(s2FiresThisBall),
                  static_cast<unsigned long>(s2SuppressedCooldown),
                  static_cast<unsigned long>(s2SuppressedWindow),
                  static_cast<unsigned long>(s2SuppressedBall));

    if (matrixSwitchSuppressedBurst > 0) {
        Serial.printf("Matrix switch burst filter: dropped=%lu (max rising edges per poll=%u)\n",
                      static_cast<unsigned long>(matrixSwitchSuppressedBurst),
                      static_cast<unsigned>(MATRIX_MAX_RISING_EDGES_PER_POLL));
    }

    matrixSwitchEdgesThisWindow = 0;
    matrixSwitchLoggedThisWindow = 0;
    matrixSwitchLogSuppressedDebounce = 0;
    matrixSwitchLogSuppressedRate = 0;
    matrixSwitchSuppressedBurst = 0;
    matrixSwitchSuppressedLampEcho = 0;
    s20OutholeSuppressedSticky = 0;
    s2SuppressedCooldown = 0;
    s2SuppressedWindow = 0;
    s2SuppressedBall = 0;
    matrixSwitchLogWindowStartMs = now;
}

void updateOtaVisual(uint32_t now) {
    if (now - lastOtaVisualToggleMs < CAPTAIN_OTA_VISUAL_INTERVAL_MS) {
        return;
    }

    lastOtaVisualToggleMs = now;
    otaVisualState = !otaVisualState;
    updateHeadboxLamps(otaVisualState ? 0xFFFF : 0x0000);
    updateLEDScore(otaVisualState ? 888888 : 0);
}

void initWifiAndOta() {
    if (!CAPTAIN_OTA_ENABLED) {
        return;
    }

    WiFi.mode(WIFI_STA);
    WiFi.begin(CAPTAIN_WIFI_SSID, CAPTAIN_WIFI_PASSWORD);

    const uint32_t started = millis();
    while (WiFi.status() != WL_CONNECTED && millis() - started < CAPTAIN_WIFI_CONNECT_TIMEOUT_MS) {
        delay(250);
    }

    if (WiFi.status() != WL_CONNECTED) {
        Serial.println("OTA/WiFi: connect timeout, OTA disabled");
        return;
    }

    ArduinoOTA.setHostname(CAPTAIN_OTA_HOSTNAME);
    ArduinoOTA.setPassword(CAPTAIN_OTA_PASSWORD);

    ArduinoOTA.onStart([]() {
        otaInProgress = true;
        lastOtaVisualToggleMs = millis();
        otaVisualState = false;
        Serial.println("OTA start");
    });
    ArduinoOTA.onEnd([]() {
        otaInProgress = false;
        updateHeadboxLamps(0x0000);
        Serial.println("OTA complete");
    });
    ArduinoOTA.onError([](ota_error_t error) {
        otaInProgress = false;
        updateHeadboxLamps(0x0000);
        Serial.printf("OTA error: %u\n", static_cast<unsigned>(error));
    });

    ArduinoOTA.begin();
    otaReady = true;
    Serial.printf("OTA ready: host=%s ip=%s\n", CAPTAIN_OTA_HOSTNAME, WiFi.localIP().toString().c_str());
}
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
void loop() {
    vTaskDelay(portMAX_DELAY);
}

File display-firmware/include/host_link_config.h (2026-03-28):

#ifndef HOST_LINK_CONFIG_H
#define HOST_LINK_CONFIG_H

// =============================================================================
// Host-Link SPI Slave + Handshake GPIO Configuration
// Target: ESP32-C6 DevKitM (Amazon clone, "C6 Mini")
// =============================================================================
//
// ESP32-C6 strapping-pin analysis (why GPIO0/GPIO1 are chosen):
//
//   GPIO8  – strapping pin: selects JTAG signal source at reset.
//             Driving it LOW externally routes JTAG to IO pins (can disrupt
//             USB-JTAG-based flashing).  → DO NOT use as handshake.
//
//   GPIO9  – strapping pin: boot-mode selector.  HIGH = SPI-Flash boot
//             (normal); LOW = Download/flash mode.  This is the BOOT button.
//             If the other board drives GPIO9 LOW during reset the chip will
//             enter download mode and refuse to boot normally.  → DO NOT use.
//
//   GPIO0  – NOT a strapping pin on ESP32-C6.  Safe to use as a handshake
//             line.  During reset the host board must hold this pin as an
//             input (high-Z), or a 10 kΩ pull-down keeps it at idle (LOW).
//
//   GPIO1  – NOT a strapping pin on ESP32-C6.  Safe as a handshake output
//             from the display side.  Drive LOW until firmware is ready.
//
// ─── Host-link SPI (display = SPI slave, host = SPI master) ─────────────────
//
//   GPIO4  MISO   – display → host data
//   GPIO5  CS     – active-LOW chip select, driven by host
//   GPIO6  MOSI   – host → display data
//   GPIO7  CLK    – SPI clock, driven by host
//
// ─── Handshake lines ─────────────────────────────────────────────────────────
//
//   GPIO0  HOST_REQ   – Host → Display, active-HIGH
//                       Host asserts HIGH to request a SPI transaction.
//                       Display polls/interrupts on this pin before clocking.
//                       Add 10 kΩ pull-down on display-board side so the pin
//                       reads LOW (idle) when the host board is unpowered or
//                       in reset.
//                       Add 470 Ω series resistor at the host-board output.
//
//   GPIO1  DISP_READY – Display → Host, active-HIGH
//                       Display drives HIGH when TX/RX buffers are prepared
//                       and a transaction can begin.  Host must only assert
//                       CS and start clocking after DISP_READY is HIGH.
//                       Display drives LOW on reset/init and immediately after
//                       a completed transaction until next buffer is queued.
//                       Add 470 Ω series resistor at the display-board output.
//
// ─── Electrical recommendations ──────────────────────────────────────────────
//
//   • 470 Ω series resistor on every inter-board signal (both SPI and handshake).
//   • 10 kΩ pull-down on HOST_REQ (GPIO0) at the display board so the pin
//     never floats when the host is unpowered.
//   • No strong pull-ups on GPIO0 or GPIO1 — idle state must be LOW.
//   • At power-on/reset both handshake pins must be high-Z or LOW; they must
//     NEVER be driven HIGH by external circuitry before firmware runs.
//   • Keep GPIO8 and GPIO9 free of external load at all times.
//
// =============================================================================

#include <Arduino.h>

// ─── SPI slave pins ───────────────────────────────────────────────────────────
constexpr uint8_t HOSTLINK_SPI_MISO_PIN = 4;
constexpr uint8_t HOSTLINK_SPI_CS_PIN   = 5;   // active-LOW, driven by host
constexpr uint8_t HOSTLINK_SPI_MOSI_PIN = 6;
constexpr uint8_t HOSTLINK_SPI_CLK_PIN  = 7;

// ─── Handshake pins ──────────────────────────────────────────────────────────
// HOST_REQ:   INPUT  on display board, OUTPUT on host board.
// DISP_READY: OUTPUT on display board, INPUT  on host board.
constexpr uint8_t HOSTLINK_HOST_REQ_PIN   = 0;   // Host → Display, active-HIGH
constexpr uint8_t HOSTLINK_DISP_READY_PIN = 1;   // Display → Host, active-HIGH

// ─── Polarity ─────────────────────────────────────────────────────────────────
// Both handshake lines are active-HIGH (1 = asserted, 0 = idle).
constexpr bool HOSTLINK_HANDSHAKE_ACTIVE_HIGH = true;

// ─── SPI transaction parameters ───────────────────────────────────────────────
constexpr uint32_t HOSTLINK_SPI_MAX_FREQ_HZ  = 10000000UL;  // 10 MHz max
constexpr uint8_t  HOSTLINK_SPI_MODE         = SPI_MODE0;
constexpr uint8_t  HOSTLINK_SPI_BIT_ORDER    = MSBFIRST;

// ─── Handshake timing ────────────────────────────────────────────────────────
// Maximum time the display will wait after asserting DISP_READY before it
// de-asserts (timeout guard, ms).
constexpr uint32_t HOSTLINK_READY_TIMEOUT_MS  = 100;
// Minimum LOW time (idle) on DISP_READY after a completed transaction before
// the next can be advertised (de-glitch gap, ms).
constexpr uint32_t HOSTLINK_READY_DEGLITCH_MS = 1;

#endif // HOST_LINK_CONFIG_H

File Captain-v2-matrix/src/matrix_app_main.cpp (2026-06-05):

#ifndef CAPTAIN_MATRIX_BAREBONES

#include <inttypes.h>
#include <string.h>

#include "esp_log.h"
#include "esp_rom_sys.h"
#include "esp_timer.h"
#include "driver/gpio.h"
#include "driver/i2c.h"
#include "driver/rmt_encoder.h"
#include "driver/rmt_tx.h"
#include "freertos/FreeRTOS.h"
#include "freertos/task.h"

#include "captain_mapping.h"
#include "captain_protocol.h"
#include "i2c_bus_config.h"
#include "matrix_lamp_driver_config.h"

namespace {
constexpr char TAG[] = "captain_matrix";
constexpr uint32_t LOOP_DELAY_US = 5000;
constexpr uint32_t OLED_REFRESH_MS = 250;
constexpr uint32_t MATRIX_LINK_LOG_MS = 1000;
constexpr uint32_t MATRIX_STATUS_HEARTBEAT_MS = 500;
constexpr gpio_num_t MATRIX_STATUS_RGB_PIN = GPIO_NUM_8;
// Bench toggles: keep these explicit so gameplay lamp behavior can be isolated
// from periodic status/diagnostic work without code surgery.
constexpr bool MATRIX_ENABLE_STATUS_HEARTBEAT = false;
constexpr bool MATRIX_ENABLE_LINK_LOG = false;
constexpr bool MATRIX_ENABLE_PERIODIC_IDLE_YIELD = false;
constexpr uint16_t MATRIX_LAMP_PULSE_MIN_US = 100;
constexpr uint16_t MATRIX_LAMP_PULSE_STEP_US = 100;
constexpr uint16_t MATRIX_LAMP_PULSE_MAX_US = 600;
constexpr uint16_t MATRIX_ROW_BLANK_US = 50;
constexpr uint16_t MATRIX_ROW_SETTLE_US = 50;
constexpr uint16_t MATRIX_ROW_POST_HOLD_US = 50;
constexpr uint8_t MATRIX_SWITCH_DEBOUNCE_TICKS = 4;
// Safety-limited proof mode: one row/column path, low duty, short timeout.
constexpr bool MATRIX_SAFE_PROOF_MODE = false;
constexpr uint8_t MATRIX_SAFE_PROOF_ROW = 4;  // 0-based (Row 5)
constexpr uint8_t MATRIX_SAFE_PROOF_COL = 4;  // 0-based (L20)
constexpr uint32_t MATRIX_SAFE_PROOF_DURATION_MS = 2000;
constexpr uint32_t MATRIX_SAFE_PROOF_PERIOD_US = 5000;
constexpr uint32_t MATRIX_SAFE_PROOF_ON_US = 1000;  // 20% duty
// Guarded boot test: briefly drive one known lamp at low energy, then force all-off.
constexpr bool MATRIX_DIAG_GUARDED_BOOT_TEST = false;
constexpr uint8_t MATRIX_DIAG_BOOT_TEST_ROW = 4;   // 0-based row index (Row 5)
constexpr uint8_t MATRIX_DIAG_BOOT_TEST_COL = 4;   // 0-based lamp column index (L20)
constexpr bool MATRIX_DIAG_BOOT_TEST_SWEEP_COLS = true;
constexpr uint8_t MATRIX_DIAG_BOOT_TEST_PULSE_LEVEL = 6;
constexpr uint32_t MATRIX_DIAG_BOOT_TEST_COL_STEP_MS = 600;
constexpr uint32_t MATRIX_DIAG_BOOT_TEST_COLUMN_PERIOD_US = 2500;
constexpr uint32_t MATRIX_DIAG_BOOT_TEST_COLUMN_ON_US = 500;  // 20% duty
constexpr uint32_t MATRIX_DIAG_BOOT_TEST_DURATION_MS =
    MATRIX_DIAG_BOOT_TEST_SWEEP_COLS ? (MATRIX_DIAG_BOOT_TEST_COL_STEP_MS * CAPTAIN_LAMP_COLS) : 5000;
// Bench-only mode to force one lamp path for conduction debugging.
constexpr bool MATRIX_DIAG_FORCE_SINGLE_LAMP = false;
constexpr bool MATRIX_DIAG_SKIP_SWITCH_SCAN = false;
constexpr uint8_t MATRIX_DIAG_FORCE_ROW = 4;   // 0-based row index (4 => Row 5)
constexpr uint8_t MATRIX_DIAG_FORCE_COL = 4;   // 0-based lamp column index (4 => L20)
constexpr uint8_t MATRIX_DIAG_FORCE_PULSE_LEVEL = 10;
// When true, bypass scan pulsing and hold one row/col frame continuously for DMM checks.
constexpr bool MATRIX_DIAG_HOLD_ONE_LAMP_DC = false;
// Keep row asserted while pulsing only the selected column for visible burn testing.
constexpr bool MATRIX_DIAG_HOLD_ROW_PULSE_COLUMN = false;
constexpr uint32_t MATRIX_DIAG_COLUMN_PULSE_PERIOD_US = 3000;
constexpr uint32_t MATRIX_DIAG_COLUMN_PULSE_ON_US = 2000;
// Shift-register drive mapping (set from bench results).
constexpr bool MATRIX_SR_CHAIN_IS_COL_THEN_ROW = true;
constexpr bool MATRIX_SR_ROW_ACTIVE_LOW = false;
constexpr bool MATRIX_SR_COL_ACTIVE_LOW = false;
constexpr i2c_port_t MATRIX_I2C_PORT = I2C_NUM_0;
constexpr size_t MATRIX_I2C_RX_BUFFER = 128;
constexpr size_t MATRIX_I2C_TX_BUFFER = 128;
constexpr uint32_t OLED_SW_I2C_DELAY_US = 4;
constexpr uint8_t OLED_I2C_SDA_PIN = 7;
constexpr uint8_t OLED_I2C_SCL_PIN = 6;
// OLED drawing is bit-banged and can pause scan refresh for ~100ms bursts.
// Disable during lamp bring-up to keep row/column timing continuous.
constexpr bool CAPTAIN_MATRIX_ENABLE_OLED_DIAGNOSTICS = false;
constexpr uint8_t OLED_ADDR_A = 0x3C;
constexpr uint8_t OLED_ADDR_B = 0x3D;

uint8_t lampRowRam[CAPTAIN_LAMP_ROWS] = {};
uint8_t switchStateBytes[CAPTAIN_SWITCH_BYTES] = {};
uint8_t switchSampleBits[CAPTAIN_SWITCH_BYTES] = {};
uint8_t debounceCandidateBits[CAPTAIN_SWITCH_BYTES] = {};
uint8_t debounceTickCounters[CAPTAIN_SWITCH_ROWS * CAPTAIN_SWITCH_COLS] = {};
uint8_t registerPointer = CAPTAIN_MATRIX_REG_SWITCH_BASE;
uint8_t lampPulseWidthLevel = CAPTAIN_MATRIX_DEFAULT_PULSE_WIDTH_LEVEL;
// Default enabled for bench bring-up so lamps can respond without extra setup commands.
bool matrixSystemEnabled = true;
bool matrixOutputEnabled = true;
uint32_t matrixI2CRxPacketCount = 0;
uint32_t matrixLampWriteBurstCount = 0;
uint32_t matrixLampWriteByteCount = 0;
uint8_t matrixLastCommand = 0;
uint32_t matrixLastLinkLogMs = 0;
rmt_channel_handle_t matrixStatusLedChannel = nullptr;
rmt_encoder_handle_t matrixStatusLedEncoder = nullptr;
bool matrixStatusLedOn = false;
uint32_t matrixLastStatusHeartbeatMs = 0;
bool safeProofActive = false;
uint64_t safeProofEndUs = 0;
bool diagBootTestActive = false;
uint64_t diagBootTestEndUs = 0;
bool oledReady = false;
uint8_t oledAddress = 0;
uint32_t lastOledRefreshMs = 0;

uint8_t guardedBootTestColumn() {
    uint8_t bootCol = MATRIX_DIAG_BOOT_TEST_COL;
    if (MATRIX_DIAG_BOOT_TEST_SWEEP_COLS) {
        const uint64_t nowUs = static_cast<uint64_t>(esp_timer_get_time());
        const uint64_t elapsedUs = nowUs >= diagBootTestEndUs
                                       ? static_cast<uint64_t>(MATRIX_DIAG_BOOT_TEST_DURATION_MS) * 1000ULL
                                       : (static_cast<uint64_t>(MATRIX_DIAG_BOOT_TEST_DURATION_MS) * 1000ULL) -
                                             (diagBootTestEndUs - nowUs);
        const uint32_t elapsedMs = static_cast<uint32_t>(elapsedUs / 1000ULL);
        const uint32_t step = elapsedMs / MATRIX_DIAG_BOOT_TEST_COL_STEP_MS;
        bootCol = static_cast<uint8_t>(step % CAPTAIN_LAMP_COLS);
    }
    return bootCol;
}
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

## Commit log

2026-02-05 Initial commit: Working RTOS firmware with External Flash OTA
    - All 5 RTOS tasks enabled (Audio, Matrix, Display, I/O, Game Logic)
    - External Flash OTA functional (W25Q64 8MB SPI flash)
    - Pre-erase optimization implemented (fixes sector race condition)
    - 100uF capacitor required at W25Q64 VCC (hardware fix documented)
    - Switch Mapping Mode disabled by default (enable with M command)
    - Clean production logging (92% reduction from debug version)
    - Comprehensive lessons learned documentation included
    [Battery charger.kicad_pcb, Battery charger.kicad_sch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]
2026-03-26 Normalize archive folder placement under archive/
    [Battery charger.kicad_pcb, Battery charger.kicad_sch]
2026-03-26 Normalize hardware files into kicad, gerbers, and backups structure
    [ESP32Vroom-B_Cu.gbl, ESP32Vroom-B_Cu.gbr, ESP32Vroom-B_Mask.gbr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]
2026-03-28 Add SPI handshake GPIO lines (GPIO0/IDC5=REQUEST, GPIO1/IDC9=READY) for display ESP32-C6
    Agent-Logs-Url: https://github.com/Phil-CIA/Captain-Fantastic-home-edition/sessions/c73ee4a7-705f-42b4-a4d8-dc867cf9c033
2026-03-28 feat(display-firmware): add GPIO0/GPIO1 handshake config and display-firmware scaffold for ESP32-C6
    Agent-Logs-Url: https://github.com/Phil-CIA/Captain-Fantastic-home-edition/sessions/0cddfb96-9512-4917-9402-31c3dfc88227
2026-03-31 Add files via upload
    Initial commit
    [Hat board.kicad_pcb, Hat board.kicad_sch]
2026-03-31 Add files via upload
    matrix board files
    [Pinball matrix board.kicad_pcb, Pinball matrix board.kicad_sch]
2026-03-31 Add files via upload
    display board commit
    [7 Seg project.kicad_pcb, 7 Seg project.kicad_sch]
2026-03-31 Add files via upload
    conrtol board
    [Pinball Control board.kicad_pcb, Pinball Control board.kicad_sch]
2026-03-31 refactor(hardware): Organize v2 boards into clean kicad/ structure
    - Move Pinball Control board → hardware/kicad/captain_control/ (main ESP32)
    - Move Pinball matrix board → hardware/kicad/captain_matrix/ (matrix ESP32)
    - Move 7 Seg project → hardware/kicad/7seg_display/ (I2C HT16K33 display)
    - Archive Hat board → hardware/kicad/legacy/ (old single-board design)
    Update documentation to reflect v2 hardware layout:
    - hardware/README.txt: describe new board locations and roles
    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
    [7 Seg project.kicad_pcb, 7 Seg project.kicad_sch, Hat board.kicad_pcb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]
2026-03-31 feat(matrix): add HT16K33-style matrix interface, test harness, and board-specific projects
2026-03-31 refactor(screenshots): organize schematic photographs into hardware folder
2026-03-31 refactor(hardware): organize .net schematic netlists into board-specific folders
2026-03-31 feat(alignment): sync control audio and matrix C6 pin mapping with schematics
2026-03-31 feat(matrix-idf): scaffold ESP32-C6 ESP-IDF baseline without explicit FreeRTOS loop APIs
2026-03-31 feat(matrix-idf): port register I2C, switch scan, and lamp refresh into C6 ESP-IDF app
2026-04-01 Captain-v2 C6 bring-up: UART workflow, strap fix docs, matrix remap scaffold
    [idf_main.cpp, idf_matrix_main.cpp]
2026-04-30 matrix bring-up: align pin map to current schematic, add SR mapping controls, and add 2026-04-30 handoff
2026-05-01 Add bare-bones matrix test track and 2026-05-01 handoff
2026-05-02 barebones: add column-595 isolation test mode, arm outputs, set chain col-then-row
    - Add BarebonesTestMode enum: Column595Isolation and SingleLampPulse
    - Default mode set to Column595Isolation
    - TEST_ENABLE_OUTPUTS = true (armed for bench test)
    - TEST_FORCE_OE_LOW_WHEN_ENABLED = true (OE held steady low, no blanking)
    - SR_CHAIN_IS_COL_THEN_ROW = true (aligns with U4->U5 schematic chain)
    - Pattern: 0xAA, 0x55, walking 1s 0x01..0x80, 700ms hold per step
    - Proven result (2026-05-02): U5 Q0..Q3 latch and hold correctly on RCLK
    - Q0 confirmed = bit8 in 16-bit frame with current chain order
    - OE confirmed steady low during active test
    [matrix_barebones_main.cpp]
2026-05-03 matrix barebones: lock baseline_2026_05_03_low_stress profile
    - Pin profile name tag and log it at boot for firmware identification
    - Reduce TEST_ON_US from 350ms to 180ms to protect bulbs during bring-up
    - Walk timing unchanged: 1s period, phased row-settle sequence
    - Polarity/chain settings verified working on hardware (first lamp lit)
    - SR_CHAIN_IS_COL_THEN_ROW=true, ROW/COL active-high confirmed good
    - Paused here: stable known-good baseline flashed to COM4
2026-05-04 matrix barebones: Phase 1 - ControlDrivenScan canonical runtime sequence
    New mode: BarebonesTestMode::ControlDrivenScan (active)
    Implements the canonical production row-scan sequence entirely in barebones
    outside app_main - same pattern as refreshLampMatrixStep() in production but
    validated independently on proven bring-up polarity/chain settings before any
    changes to the production runtime.
    State sequence per row (A->B->C->D):
    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
2026-05-04 matrix barebones: Phase 2 matrix-pattern fast scan validated
    - Keep ControlDrivenScan as active test mode
    - Fast multiplex timings for persistence-of-vision (100us blank, 100us settle, 700us on, 100us post-hold)
    - Replace headbox chase feed with matrix control pattern source (mirrors writeMatrixCommand)
    - Pattern now drives row-byte lamp data matching matrix domain (not headbox LEDs)
    - Serial command path remains disabled by default; script source drives lampRam for deterministic bench tests
    - Hardware validation confirmed: expected row scan and visible lamp behavior
    [matrix_barebones_main.cpp]
2026-05-05 matrix: apply logical-to-physical col remap (drop col0, shift cols 1-4 to 0-3)
    Hardware-verified on bench: physical lamp column harness is offset by +1
    from software addressing. Fix: remapLogicalToPhysicalCols() shifts the
    logical col mask right by 1 bit at SR frame compose time.
    - matrix_app_main.cpp: remap applied inside composeShiftFrame() so all
    scan paths (normal, diag, boot test, safe proof) are covered
    - matrix_barebones_main.cpp: remap applied in runTargetLampSequenceLoop();
    full 23-lamp playfield sequence confirmed working on hardware
    - platformio.ini: default_envs restored to captain_matrix_idf
    Restore point: production firmware uploaded to COM4, all 23 playfield
    LEDs verifie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
    [matrix_app_main.cpp, matrix_barebones_main.cpp]
2026-05-05 matrix: fix LED flicker and reduce brightness for 18V operation
    Phase 8 - multiplex LED brightness tuning (2026-05-05)
    - CDS_COLUMN_ON_US: 700us -> 350us (~35% duty cycle per row slot)
    LEDs are automotive 12V-rated running at 18V; halved on-time keeps
    brightness acceptable without over-driving them further
    - vTaskDelay yield: every 10 cycles (~80ms gap) -> every 250 cycles (~1.3s)
    10ms dark gap every 80ms was visible flicker with LEDs (no thermal lag
    unlike tungsten). At 250 cycles the gap is imperceptible.
    - TEST_PROFILE_NAME updated to phase8_multiplex_led_brightness_2026_05_05
    Hardware-verified on bench: L2/L7/L10/L20 blinking at 500ms, no flicker,
    brightness suitable. Lamp pa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
    [matrix_barebones_main.cpp]
2026-05-05 matrix: fix production scan vTaskDelay flicker; restore default_envs
    - matrix_app_main.cpp: replace bare vTaskDelay(1) every loop with
    counter-gated yield every 250 refreshLampMatrixStep() calls (~1.3s
    between 10ms gaps). Same fix as barebones firmware. Eliminates LED
    flicker visible at 12Hz with no thermal lag (unlike tungsten).
    Production firmware uploaded to COM4 at this commit.
    Ready for control board (COM5) I2C integration.
    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
    [matrix_app_main.cpp]
2026-05-05 control: replace fixed matrix lamp write with explicit blink bring-up quartet
    - Remove hardcoded always-on test set that forced matrix lamps each poll
    (L22, L2, L13), which could be mistaken for stale lamp data.
    - Add deterministic link bring-up blink pattern at 500ms:
    L2, L7, L10, L20 (same quartet validated on matrix board tests).
    - writeMatrixCommand now takes current time and toggles lamp rows on/off
    each half-second for clear I2C link visibility.
    Build passes for captain_control. Upload to COM5 currently blocked by
    serial transport instability (write timeout / device not functioning).
    [control_main.cpp]
2026-05-05 control: disable test blink for steady matrix lamps; tune COM5 upload settings
    - control_main.cpp: add MATRIX_TEST_BLINK_ENABLED=false so the matrix
    bring-up quartet (L2/L7/L10/L20) is steady instead of 500ms blink
    - platformio.ini (captain_control): keep upload_speed=57600 and use
    --no-stub upload flag to improve behavior on unstable CP210x COM5 link
    [control_main.cpp]
2026-05-05 matrix: make watchdog yield time-based to reduce periodic LED flicker
    - matrix_app_main.cpp: replace scan-cycle-based vTaskDelay(1) trigger with
    wall-clock cadence (every 2s)
    - prevents workload-dependent 10ms dark gaps (more frequent when fewer rows
    are lit), which can appear as periodic flicker with LEDs
    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
    [matrix_app_main.cpp]
2026-05-05 matrix: deterministic scan timing - fixed-slot wall-clock delays
    Key changes:
    - Add delayWallUs() helper using esp_timer_get_time() hardware counter;
    immune to I2C interrupt jitter that made esp_rom_delay_us exit early
    - All scan phases (blank, settle, pulse, post-hold) now use wall-clock delays
    - Pulse/post-hold window runs every row regardless of colMask so row slot
    duration is constant and does not vary with lamp pattern density
    - serviceI2C() moved to once per 8-row cycle to avoid per-row mutex overhead
    - OLED diagnostics disabled to eliminate 100ms bit-bang stalls
    - Reduce default pulse level 4->3 (500us->400us) to reduce ghosting
    - captain_protocol.h: CAPTAIN_MATRIX_DEFAULT_PULSE_W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
    [matrix_app_main.cpp]
2026-05-12 matrix: implement WS2812 heartbeat on GPIO8 via native RMT; control: move heartbeat to GPIO16 (GPIO2 conflict resolution); add handoff documentation
    [RESOURCE_TABLE.csv]
2026-05-13 2026-05-13: Remove unused scanSwitchMatrix() function (wrapped with #if 0); verified I2C stability over 5-min extended test; all systems nominal
2026-05-13 2026-05-13: Add end-of-day handoff - confirmed LED heartbeat, cleaned unused function, validated I2C stability (5-min test, 0.005% error rate)
2026-05-13 2026-05-13: Control heartbeat LED on GPIO15 as WS2812 (NeoPixel); replace plain GPIO toggle
    [control_main.cpp]
2026-06-03 session-2026-06-03: guarded flash, build identity stamp, archive cleanup
    - Add scripts/guarded-flash.ps1: MAC-guarded PlatformIO upload wrapper
    - Add scripts/flash-targets.json: immutable MAC identity source of truth
    - Add scripts/pio_build_meta.py: inject git hash/state as CPPDEFINES
    - Control firmware: print Build: git/state/date/time on boot
    - Update Captain-v2/platformio.ini: add pio_build_meta.py extra_script
    - Update Captain-v2-matrix/platformio.ini: align to guarded workflow
    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
2026-06-05 Control: add bright graphic-zone gameplay LEDs with validated monitor workflow
2026-06-05 docs: add switch latency phase-1 scope to handoff
